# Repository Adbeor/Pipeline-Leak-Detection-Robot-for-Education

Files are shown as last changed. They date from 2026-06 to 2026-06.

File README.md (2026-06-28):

# PLDR-Edu: Open-Source Pipeline Leak Detection Robot 🤖💧

<div align="center">
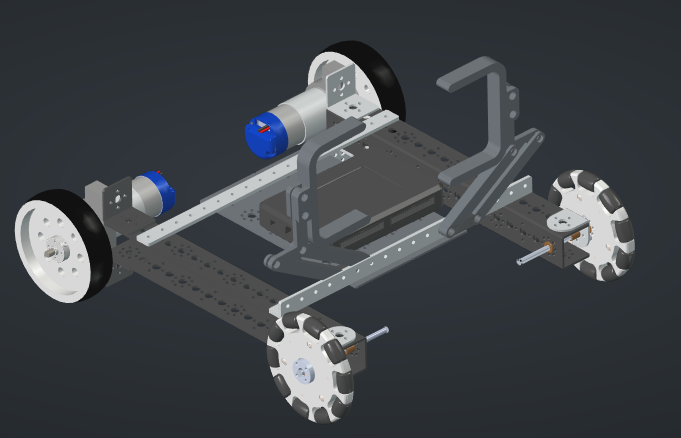
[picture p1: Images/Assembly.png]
PLDR-Edu Robot
  
</div>

This project introduces the **PLDR-Edu**, an open-source mobile robot designed as a project-based learning (PBL) platform for the **Mechatronic Systems Design** course at **UTEC**.

The system addresses the engineering challenge of inspecting a pressurized 3-inch PVC pipe and detecting simulated air leaks without human intervention. The robot encircles the pipe using a rigid two-clamp frame with 3D-printed arms, scanning it acoustically and visually without physical contact. Upon detection, a marker mechanism paints a reference dot directly on the pipe, and an acoustic alarm alerts the operator.

## 📋 Main Features & Contributions
- **Non-Contact Sweep:** The geometric constraint of the frame provides 360-degree coverage at a controlled stand-off distance. 
- **Acoustic Triangulation:** Captures and filters signals using three calibrated microphones targeting the characteristic broadband acoustic signal of pressurized air leaks.
- **Visual Confirmation:** A dedicated vision pipeline processes images to confirm the physical hole.
- **Contributions:** Generic microphone calibration process, vision-to-hardware data pipeline, and scalable scanning processes.
- **License:** CERN-OHL-P

## 🛠️ Hardware Architecture
The robot utilizes a multi-level control and processing architecture:
- **Structure & Actuation:** TETRIX® robotics kit combined with custom 3D-printed extensions.
- **Main Controller:** NI MyRIO running LabVIEW for locomotion and main logic.
- **Acoustic Processing:** ESP32 modules handling the signal from the microphones with band-pass filtering.
- **Computer Vision:** Raspberry Pi 3 (with optional Arty A7 100T FPGA support) dedicated to visual confirmation.

## 📂 Repository Structure
- `/CAD`: Individual CAD files and assemblies (.FCStd and .step formats).
- `/Electronics`: Electronic schematics and hardware files.
- `/Firmware`: Source code for the robot's control system.
- `/images`: Documentation images and renders.
- `/Docs`: Diagrams, schematics, and the full HardwareX article report.

---
*Developed by Adrian Becerra, Andrea Muñoz, Carlos Lam, Kiyomi Takahashi\**

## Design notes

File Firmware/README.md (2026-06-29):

# Firmware del Robot Inspector de Fugas de Tuberías

Este directorio contiene el firmware de control del microcontrolador **ESP32** encargado del procesamiento digital de señales acústicas (DSP) y sensores de proximidad ultrasónicos, así como las herramientas en **Python** para adquisición de datos, análisis espectral de fugas en tiempo real y visualización de registros.

---

## 📂 Estructura de Carpetas Organizada

La carpeta de Firmware se ha estructurado de la siguiente forma para separar el código de producción, los scripts de análisis y los datos recolectados:

```text
Firmware/
├── README.md               # Este archivo de documentación
└── ESP32/                  # Proyecto principal en ESP-IDF (C/C++)
    ├── main/               # Código fuente del firmware
    │   ├── main.c          # Código principal (Dual-Core: FFT + Sonar + Telemetría)
    │   ├── main_normal.c   # Versión simplificada del firmware principal
    │   ├── calibrate.c     # Rutina de calibración y prueba de sensores
    │   ├── CMakeLists.txt  # Configuración de compilación del módulo principal
    │   └── idf_component.yml # Dependencia oficial para la librería esp-dsp
    ├── scripts/            # Scripts en Python de análisis y telemetría
    │   ├── log_data.py     # Registro en vivo de telemetría UART a archivos CSV
    │   ├── plot_log.py     # Visualización gráfica de los históricos de sensores (CSV a PNG)
    │   ├── FFT.py          # Visualización en vivo y captura de espectros FFT por puerto serial
    │   ├── plot_spectrum.py # Capturador y promediador de firmas de fuga de frecuencia (Hz)
    │   └── robot_guide.py  # Script de guía interactiva durante experimentos en tuberías
    ├── data/               # Historial de registros CSV y gráficos generados
    │   ├── sensor_log_*.csv  # Logs crudos de pruebas
    │   ├── sensor_log_*.png  # Gráficas automáticas de presión y proximidad
    │   └── leak_signature_*.csv # Firmas espectrales de fugas capturadas
    ├── sdkconfig           # Configuración del proyecto ESP-IDF
    └── CMakeLists.txt      # Archivo de construcción global del proyecto
```

---

## ⚡ Arquitectura del Firmware (ESP32)

El firmware está desarrollado sobre **ESP-IDF v5.x/v6.x** utilizando capacidades **Dual-Core** y multitarea con **FreeRTOS** para garantizar procesamiento de audio en tiempo real y lecturas de telemetría sin latencia.

### Distribución de Tareas en Núcleos

```mermaid
graph TD
    subgraph ESP32
        subgraph Core0 [Core 0: Control & Telemetría]
            T1[hcsr04_uart_task]
            T1 -->|Lectura Secuencial| S1[6x Ultrasonidos HC-SR04]
            T1 -->|Envío Trama| U[UART2 TX GPIO 17]
        end
        subgraph Core1 [Core 1: Adquisición & DSP]
            T2[audio_fft_task]
            T2 -->|Lectura ADC1 CH4-7| M[4x Micrófonos Analógicos]
            T2 -->|Procesamiento| FFT[1024-pt FFT & Hann Window]
            FFT -->|Magnitud Acústica / Filtro 13-16 kHz| Q[Cola FreeRTOS]
        end
        Q -->|Resultados de FFT| T1
    end
    U -->|Trama: MAG:X.XXX,D:XX.X,P1...| myRIO[myRIO RX]
```

1. **Núcleo 1 (Procesamiento de Audio - `audio_fft_task`)**:
   - Muestrea secuencialmente **4 micrófonos analógicos** a una frecuencia de muestreo de **20 kHz por canal** usando el ADC1 (para no interferir con la antena WiFi/BT).
   - Aplica una ventana de **Hann** para reducir el leakage espectral y calcula una **FFT de 1024 puntos** por micrófono mediante hardware asistido por la librería **`esp_dsp`**.
   - Filtra y promedia las magnitudes en la banda crítica de fugas (**13 kHz – 16 kHz**).
   - Envía el promedio de la magnitud acústica (`MAG`) a una cola de FreeRTOS.

2. **Núcleo 0 (Proximidad y Telemetría - `hcsr04_uart_task`)**:
   - Realiza lecturas secuenciales de hasta **6 sensores de ultrasonido HC-SR04** para detección de obstáculos y posicionamiento del robot en la tubería.
   - Recibe la magnitud del análisis espectral de fugas (`MAG`) desde la cola.
   - Genera una trama estructurada y la envía a través de **UART2** (115200 baudios) al controlador de tracción (NI myRIO).

> [!IMPORTANT]
> **Trama de Telemetría UART:**
> `MAG:<Magnitud_Fuga>,D:<Distancia_HCSR04>,P1:<Proximidad1>,P2:<Proximidad2>,P3:<Proximidad3>\n`
> Esta trama es enviada continuamente para que el robot decida detenerse si detecta una fuga (alta `MAG`) o un obstáculo (baja `D` o valores de proximidad en `P1`/`P2`/`P3` por debajo de `PROXIMITY_THRESHOLD_CM`).

---

## 🔌 Asignación de Pines (Pinout)

Todos los sensores analógicos están conectados al bloque **ADC1** debido a restricciones de ESP-IDF cuando se activan módulos inalámbricos o de control.

| Sensor / Puerto | Pin GPIO (ESP32) | Función | Detalles / Canal ADC |
| :--- | :--- | :--- | :--- |
| **Micrófono 0** | GPIO 32 | Entrada Analógica | `ADC1_CH4` |
| **Micrófono 1** | GPIO 33 | Entrada Analógica | `ADC1_CH5` |
| **Micrófono 2** | GPIO 34 | Entrada Analógica | `ADC1_CH6` (Solo Entrada) |
| **Micrófono 3** | GPIO 35 | Entrada Analógica | `ADC1_CH7` (Solo Entrada) |
| **HC-SR04 Main (Distancia)** | TRIG: GPIO 4 / ECHO: GPIO 5 | Distancia Frontal | Sensor principal de trayectoria |
| **HC-SR04 P1** | TRIG: GPIO 18 / ECHO: GPIO 19| Detección de Pared 1 | Sensor de alineación lateral |
| **HC-SR04 P2** | TRIG: GPIO 21 / ECHO: GPIO 22| Detección de Pared 2 | Sensor de alineación lateral |
| **HC-SR04 P3** | TRIG: GPIO 23 / ECHO: GPIO 25| Detección de Pared 3 | Sensor de alineación lateral |
| **UART2 TX** | GPIO 17 | Transmisión de datos | Conexión al RX del controlador myRIO |
| **UART2 RX** | GPIO 16 | Recepción de datos | Sin uso en la versión actual |

---

## 🛠️ Compilación y Flasheo del Firmware

Se requiere tener instalado el entorno **ESP-IDF** (versión 5.1 o superior recomendada).

```bash
# 1. Navegar al proyecto ESP32
cd Firmware/ESP32

# 2. Configurar la arquitectura (ESP32 clásica)
idf.py set-target esp32

# 3. Compilar el proyecto
idf.py build

# 4. Flashear y abrir el monitor serial
# Reemplaza /dev/ttyUSB0 con tu puerto local asignado
idf.py -p /dev/ttyUSB0 flash monitor
```

---

## 🐍 Guía de Uso de Herramientas Python (scripts/)

Los scripts de Python permiten registrar y graficar experimentos en tiempo real conectando el ESP32 a la computadora vía USB-Serial.

> [!NOTE]
> Todos los scripts de Python han sido actualizados para guardar sus salidas automáticamente dentro de la carpeta `Firmware/ESP32/data/` para mantener ordenada la raíz del proyecto.

### 1. Visualización de Espectro en Tiempo Real (`FFT.py`)
Muestra un gráfico dinámico del espectro de frecuencia capturado por los micrófonos del robot.
```bash
python scripts/FFT.py --port /dev/ttyUSB0 --maxfreq 10000
```

### 2. Registro de Telemetría (`log_data.py`)
Captura los datos del puerto serial de telemetría y los guarda en un archivo estructurado CSV de forma continua.
```bash
python scripts/log_data.py --port /dev/ttyUSB0
# Genera: data/sensor_log_YYYYMMDD_HHMMSS.csv
```

### 3. Generación de Gráficas Estáticas (`plot_log.py`)
Genera automáticamente imágenes en formato PNG a partir de los datos crudos `.csv` guardados en la carpeta `data/`.
```bash
python scripts/plot_log.py data/sensor_log_20260619_171421.csv
# Genera: data/sensor_log_20260619_171421.png con trazas de magnitudes y distancias
```

### 4. Captura de Firmas Espectrales (`plot_spectrum.py`)
Muestra el espectro en tiempo real y permite promediar y exportar una firma de fuga definitiva.
* **Tecla `S`:** Presionar en la ventana de visualización para exportar la firma espectral promedio de la fuga a un archivo `.csv`.
```bash
python scripts/plot_spectrum.py --port /dev/ttyUSB0
# Genera: data/leak_signature_1781908096.csv
```

### 5. Guía de Experimentos (`robot_guide.py`)
Asistente interactivo en consola para documentar ensayos en la maqueta de tuberías, pidiendo descripciones de la prueba y registrando datos del comportamiento del robot paso a paso.
```bash
python scripts/robot_guide.py --port /dev/ttyUSB0
# Genera: data/robot_guide_log_YYYYMMDD_HHMMSS.csv
```

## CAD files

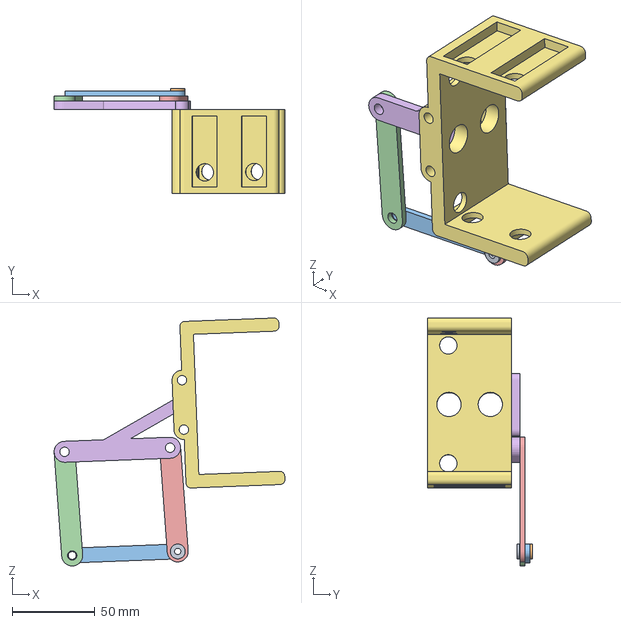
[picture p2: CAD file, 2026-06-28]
CAD/garras-Assembly.3mf
139.9 x 63.5 x 150.3 mm

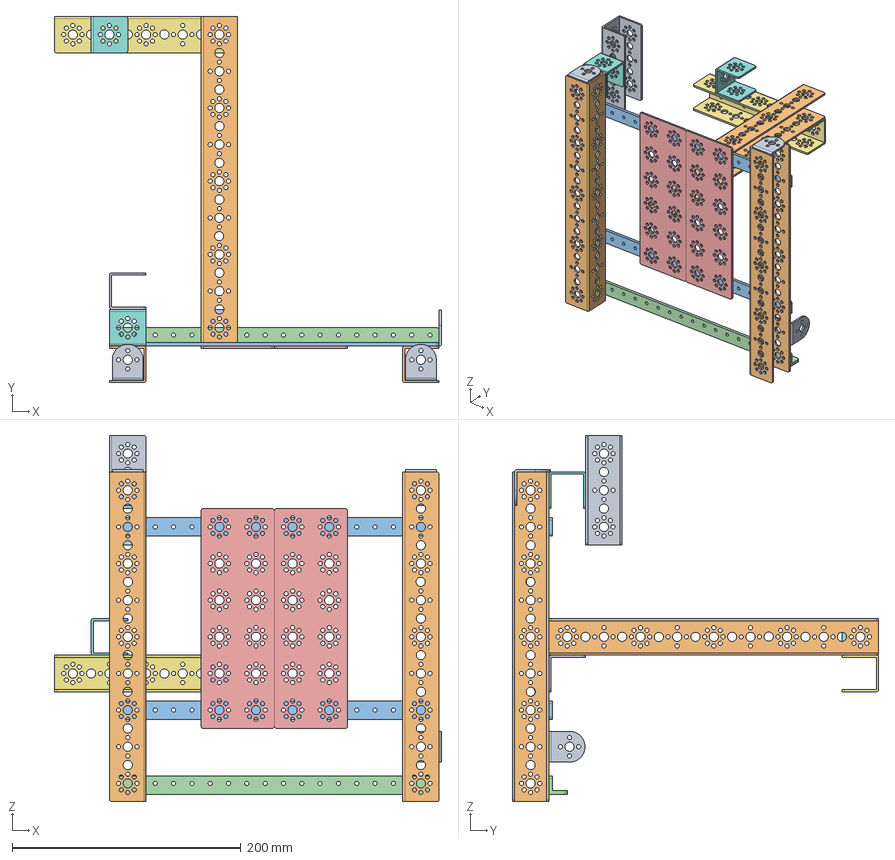
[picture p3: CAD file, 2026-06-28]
CAD/EnsambleMaestro.FCStd
338.0 x 320.0 x 320.0 mm
39062_TXM-LBrackets x 3
39068_TXM-288mmChannel x 3
39070_TXM-288mm Flat Bar x 2
39071_TXM-288mmAngle
39073_TXM-FlatBuildingPlates x 2
39281_TXM-InsideCornerBrackets
39067_TXM-160mmChannel
39065_TXM-32mmChannel x 2
39066_TXM-96mmChannel

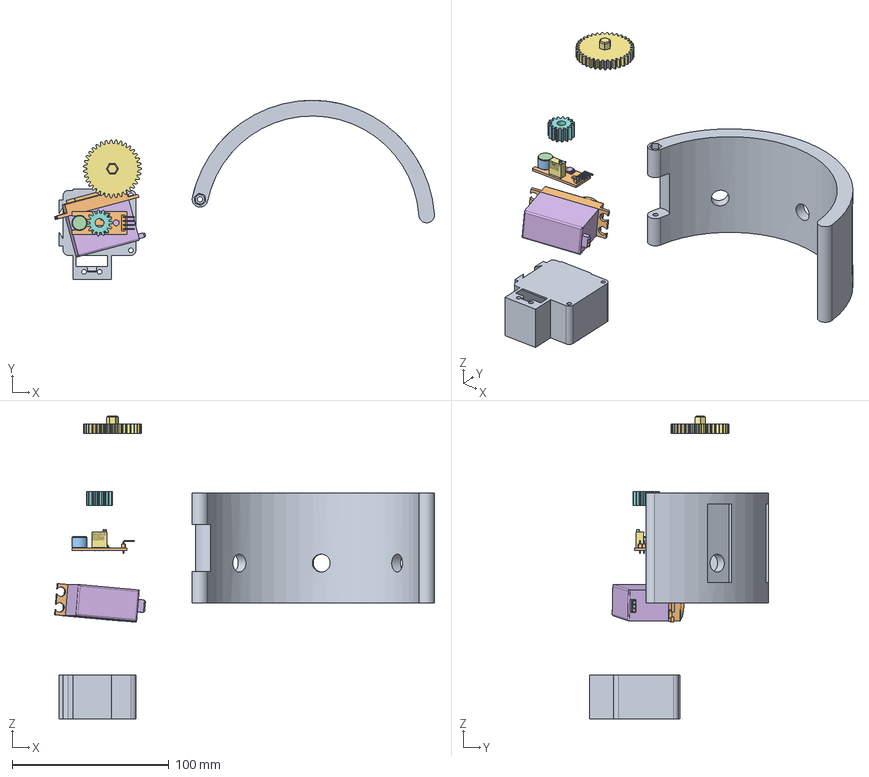
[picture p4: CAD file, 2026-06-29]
CAD/Garra2.FCStd
242.2 x 114.3 x 193.0 mm
Garra
Engrane_Garra
Engrane_servo
Base_Garra
HJX_Mike_PCB
Mike_housing
Mike_cap
Mike_terminal x 2
SOIC-8
Bao_3296_Body
Bao_3296_Adj_Trim
Bao_3296_Terminal x 3
1X4_Pin_Holder
90_Pin_M x 4

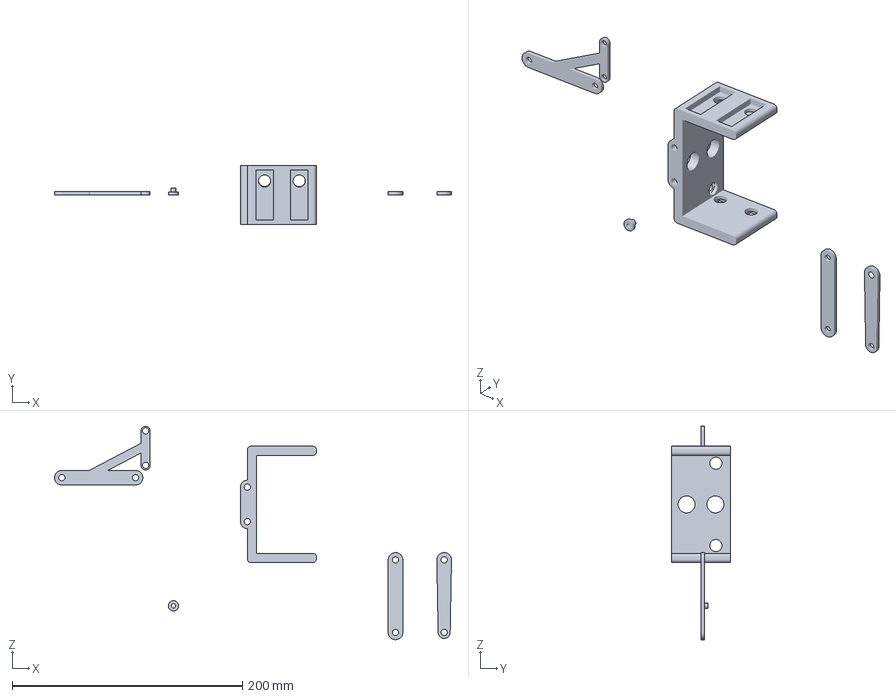
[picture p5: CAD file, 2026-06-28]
CAD/gcodes/garras-Part.3mf
344.7 x 51.0 x 185.4 mm

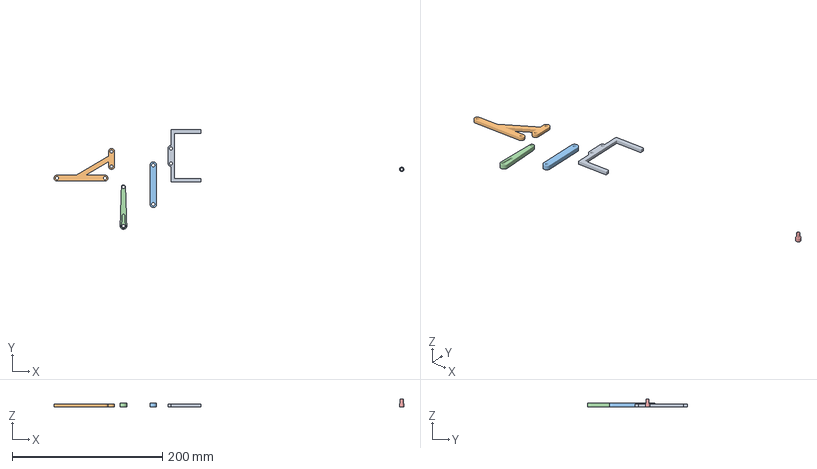
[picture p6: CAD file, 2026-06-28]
CAD/gcodes/garras-2.3mf
466.6 x 132.9 x 10.3 mm

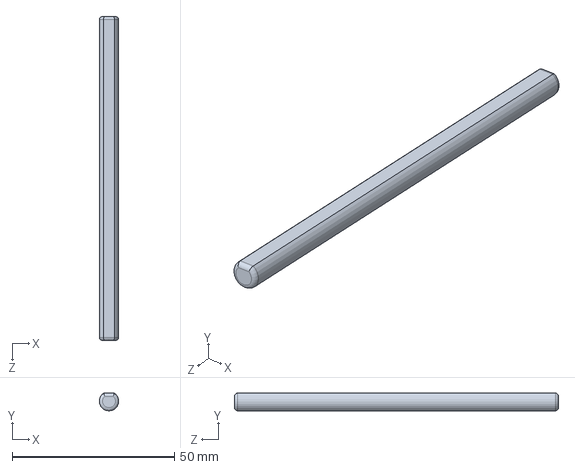
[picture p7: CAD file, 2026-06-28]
CAD/Piezas/Tetrix 6mm x 100mm Axle.SLDPRT
6.00 x 5.50 x 100.0 mm

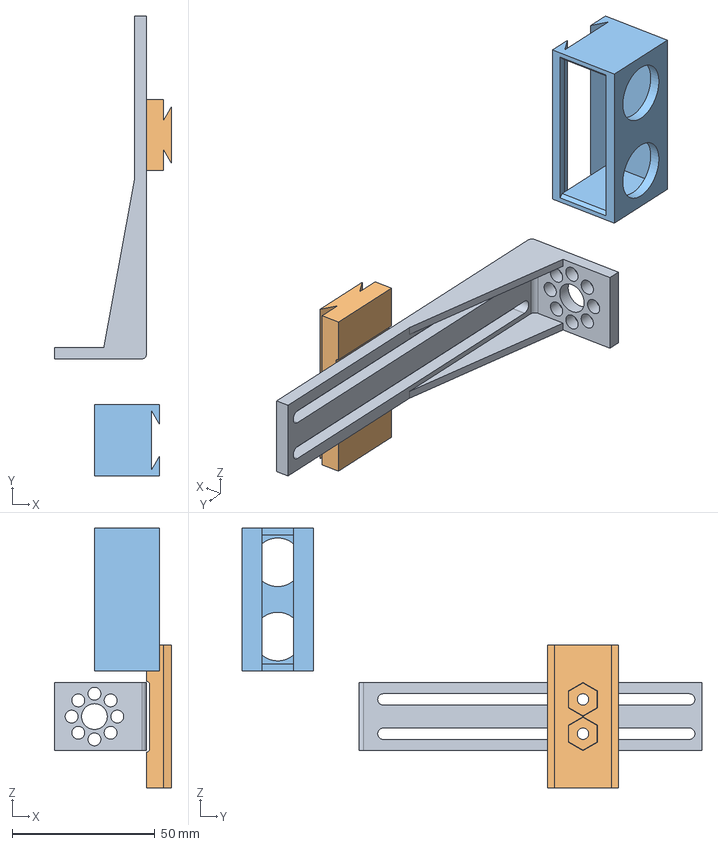
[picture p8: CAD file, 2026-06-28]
CAD/Soporte_Ultrasonido.FCStd
41.0 x 161.0 x 91.0 mm
SoporteVertical
Cuerpo001
Cuerpo002

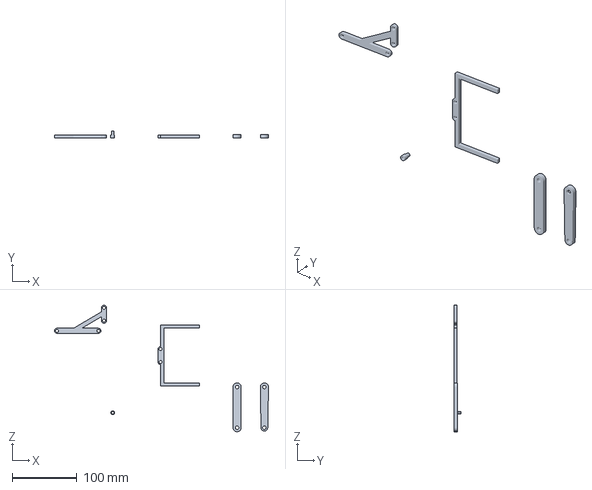
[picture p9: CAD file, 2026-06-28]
CAD/gcodes/garras-PartBody.3mf
331.7 x 10.3 x 196.2 mm

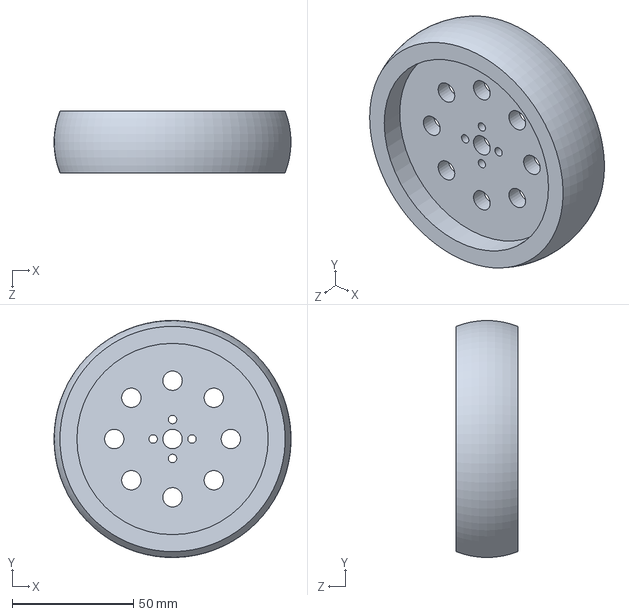
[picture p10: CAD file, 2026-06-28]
CAD/Piezas/Tetrix 4 inch Wheel.SLDPRT
97.6 x 97.6 x 25.4 mm

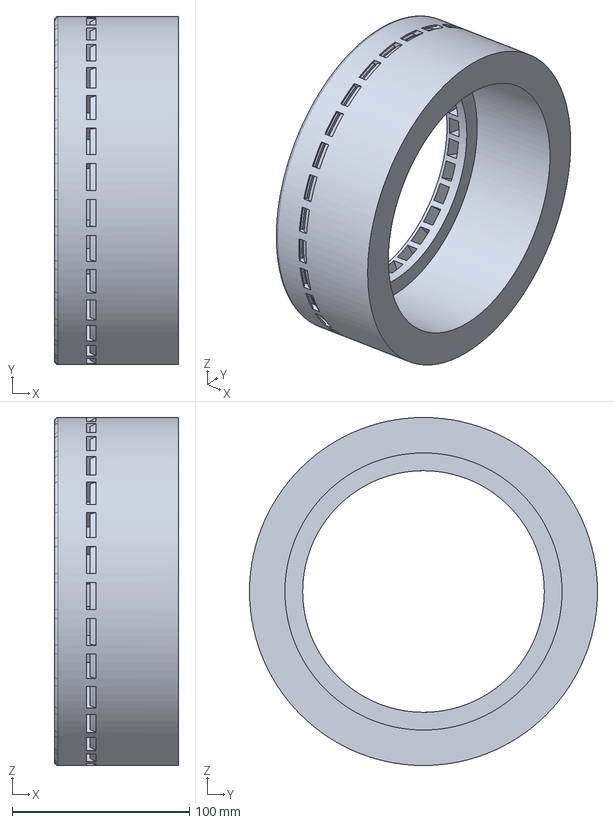
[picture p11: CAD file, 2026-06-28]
CAD/sibato.FCStd
70.0 x 196.2 x 196.2 mm

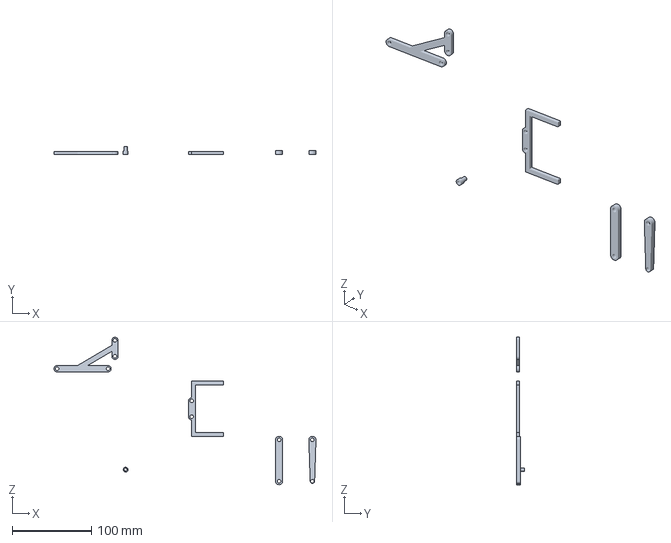
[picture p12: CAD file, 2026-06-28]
CAD/gcodes/garras-3.3mf
329.8 x 10.3 x 185.7 mm

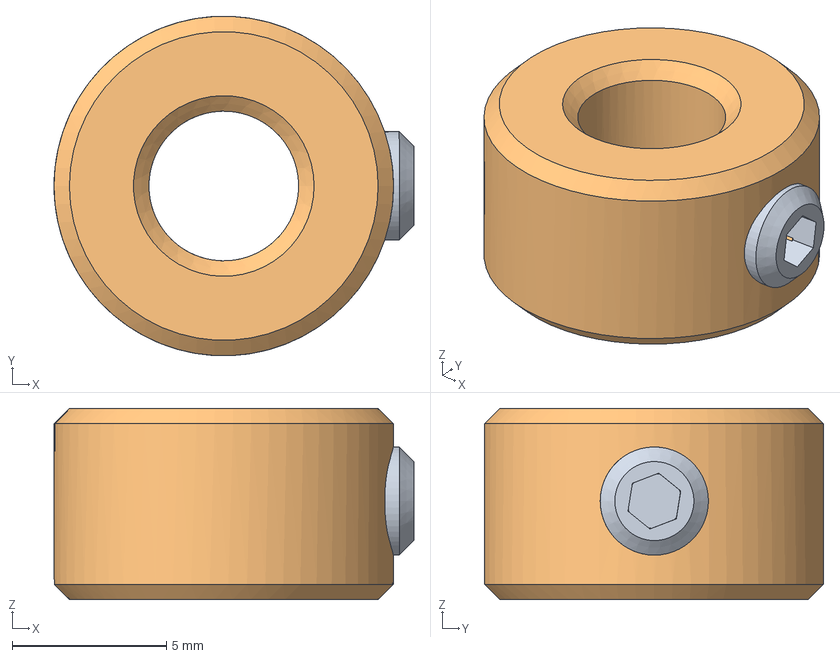
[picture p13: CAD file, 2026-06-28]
CAD/Piezas/Tetrix Axle Set Collar(2).step
11.7 x 11.0 x 6.20 mm

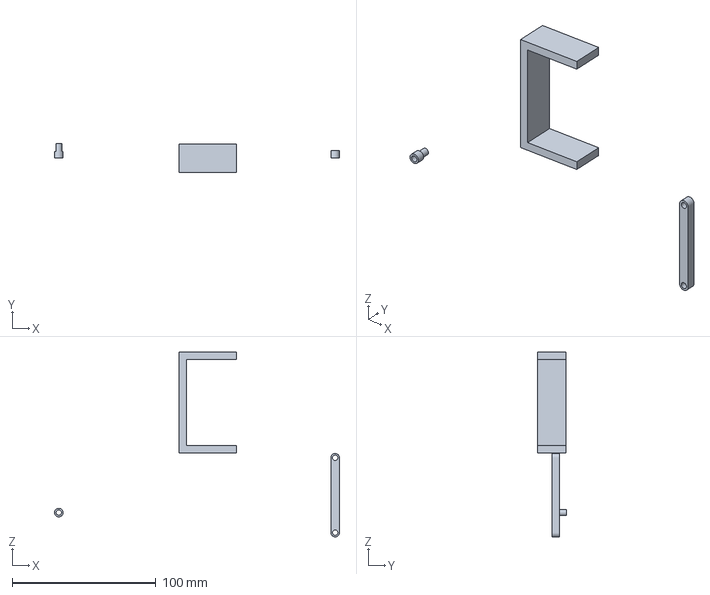
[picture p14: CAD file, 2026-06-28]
CAD/gcodes/garras_1.3mf
198.0 x 20.3 x 128.4 mm

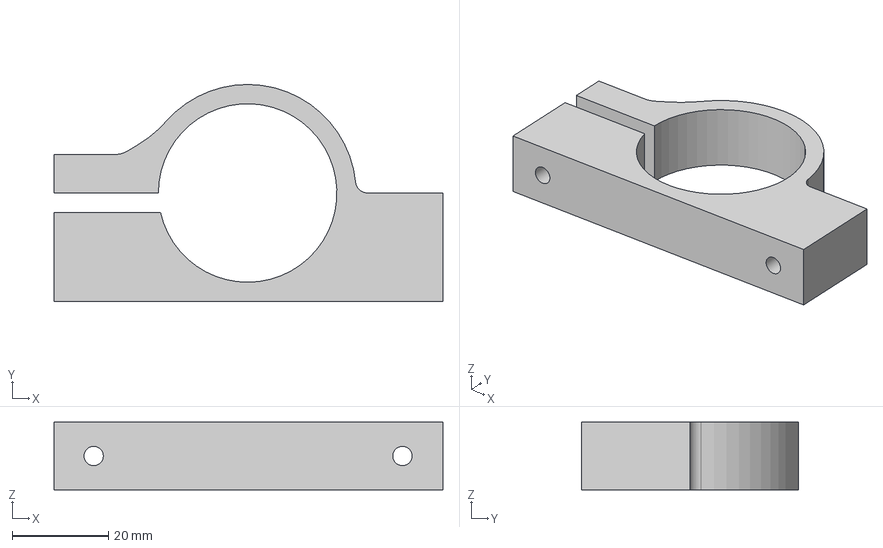
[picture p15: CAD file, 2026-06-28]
CAD/Piezas/motortarto.step
80.6 x 45.0 x 14.0 mm

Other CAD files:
CAD/gcodes/garras-4.3mf
CAD/Sin nombre.FCStd
CAD/Encaje_Motor.FCStd
CAD/gcodes/Encaje_Motor-Body.3mf
CAD/Piezas/MyRio.step
CAD/Piezas/Tetrix 4 inch Dual Omni Wheel(2).SLDPRT
CAD/Piezas/Tetrix 4 inch Dual Omni Wheel(2).step
CAD/Piezas/Tetrix 4 inch Wheel(2) - WHEEL 4.step
CAD/Piezas/Tetrix 4 inch Wheel(2).SLDPRT
CAD/Piezas/Tetrix Axle Hub With Set Screw(2) - Part 3.step
CAD/Piezas/Tetrix Axle Hub With Set Screw(2).SLDPRT
CAD/Piezas/Tetrix Axle Set Collar(2).SLDPRT
CAD/Piezas/Tetrix Bronze Bushing(2) - Chamfer1.step
CAD/Piezas/Tetrix Bronze Bushing(2).SLDPRT
CAD/Piezas/Tetrix Motor Shaft Hub With Set Screw(2).SLDPRT
CAD/Piezas/Tetrix Steel Axle 100mm(2).SLDPRT
CAD/Piezas/Tetrix Steel Axle 100mm.SLDPRT
CAD/Piezas/Tetrix TorqueNADO DC Motor(2).SLDPRT
CAD/Piezas/Tetrix TorqueNADO DC Motor(2).step
CAD/Piezas/Tetrix12V.step
CAD/Piezas/Tetrix12V_.SLDPRT
CAD/Piezas/axel.step
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

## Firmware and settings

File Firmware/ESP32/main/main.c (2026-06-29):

/**
 * @file main.c
 * @brief ESP32 Dual-Core: 4x Mic Analógico (FFT 13–16 kHz) + 4x HC-SR04
 *
 * ARQUITECTURA:
 *   Core 0 (Task: hcsr04_uart_task)
 *     - Lee 4× HC-SR04 secuencialmente
 *     - Recibe resultado FFT via Queue
 *     - Envía trama UART: MAG:X.XXX,D:XXX.X,P1:X,P2:X,P3:X\n
 *
 *   Core 1 (Task: audio_fft_task)
 *     - Muestrea 4 ADC en secuencia a ~160 kHz total (~40 kHz/canal)
 *     - Aplica ventana Hann + FFT de 1024 puntos por micrófono (esp_dsp)
 *     - Promedia magnitud en banda 13–16 kHz entre los 4 micrófonos
 *     - Envía resultado a Queue compartida
 *
 * PINES (todos en ADC1 para evitar conflicto con WiFi):
 *   Micrófonos:
 *     MIC0 → GPIO32 (ADC1_CH4)
 *     MIC1 → GPIO33 (ADC1_CH5)
 *     MIC2 → GPIO34 (ADC1_CH6)
 *     MIC3 → GPIO35 (ADC1_CH7)
 *
 *   HC-SR04 (TRIGGER / ECHO):
 *     HCSR04_MAIN (envía distancia)  → TRIG: GPIO 4  | ECHO: GPIO 5
 *     HCSR04_P1                      → TRIG: GPIO 18 | ECHO: GPIO 19
 *     HCSR04_P2                      → TRIG: GPIO 21 | ECHO: GPIO 22
 *     HCSR04_P3                      → TRIG: GPIO 23 | ECHO: GPIO 25
 *
 *   UART TX → GPIO 17 (UART2)   [conectar a RX del myRIO]
 *   UART RX → GPIO 16 (UART2)   [no usado, pero declarado]
 *
 * NOTA PINES ADC:
 *   GPIO32 y GPIO33 son bidireccionales; evita pull-ups/pull-downs activos
 *   en esos pines para no distorsionar la lectura analógica.
 *   GPIO34 y GPIO35 son input-only (no tienen driver de salida interno).
 *
 * DEPENDENCIAS (idf_component.yml o CMakeLists):
 *   - esp_adc
 *   - esp_timer
 *   - esp_dsp  (componente oficial: idf-extra-components/esp-dsp)
 *   - driver
 *   - freertos
 *
 * COMPILACIÓN:
 *   idf.py set-target esp32
 *   idf.py build flash monitor
 */

#include <stdio.h>
#include <string.h>
#include <math.h>
#include "freertos/FreeRTOS.h"
#include "freertos/task.h"
#include "freertos/queue.h"
#include "driver/gpio.h"
#include "driver/uart.h"
#include "esp_adc/adc_oneshot.h"
#include "esp_timer.h"
#include "esp_log.h"
#include "dsps_fft2r.h"   // esp-dsp: FFT radix-2
#include "dsps_wind.h"    // esp-dsp: ventanas

/* ─────────────────────────────────────────────
   CONSTANTES GENERALES
───────────────────────────────────────────── */
#define TAG                 "ESP32_SENSOR"

/* ADC / Audio */
#define NUM_MICS            4
#define FFT_SIZE            1024          // puntos por canal
#define SAMPLE_RATE_HZ      20000         // muestreo por canal (Hz) (bajado a 20 kHz para precisión del ADC)
#define BANDS_COUNT         32
#define BINS_PER_BAND       ( (FFT_SIZE / 2) / BANDS_COUNT ) // 512 / 32 = 16 bins por banda (~312.5 Hz)

static const float leak_pattern[22] = {
    0.2557f, 0.3818f, 0.1938f, 0.2244f, 0.2162f, 0.1818f, 0.2123f, 0.2085f,
    0.2575f, 0.2778f, 0.2957f, 0.2166f, 0.2527f, 0.1716f, 0.1454f, 0.1472f,
    0.1490f, 0.1499f, 0.1468f, 0.1158f, 0.1315f, 0.1473f
};

/* HC-SR04 */
#define NUM_HCSR04          6             // Número total de sensores HC-SR04
#define HCSR04_TIMEOUT_US   25000         // 25 ms → ~4.3 m máximo
#define PROXIMITY_THRESHOLD_CM 10.0f

/* UART */
#define UART_PORT           UART_NUM_2
#define UART_BAUD           115200
#define UART_TX_PIN         17
#define UART_RX_PIN         16
#define UART_BUF_SIZE       256

/* ─────────────────────────────────────────────
   PINES ADC (canales ADC1)
───────────────────────────────────────────── */
static const adc_channel_t adc_channels[] = {
    ADC_CHANNEL_4,   // GPIO32
    ADC_CHANNEL_5,   // GPIO33
    ADC_CHANNEL_6,   // GPIO34
    ADC_CHANNEL_7,   // GPIO35
};

static const gpio_num_t adc_gpios[] = {
    GPIO_NUM_32,
    GPIO_NUM_33,
    GPIO_NUM_34,
    GPIO_NUM_35,
};

/* ─────────────────────────────────────────────
   PINES HC-SR04
───────────────────────────────────────────── */
typedef struct {
    gpio_num_t trig;
    gpio_num_t echo;
} hcsr04_pins_t;

static const hcsr04_pins_t hcsr04[NUM_HCSR04] = {
    {GPIO_NUM_4,  GPIO_NUM_5},   // MAIN → envía distancia (D)
    {GPIO_NUM_18, GPIO_NUM_19},  // P1 (Derecha)
    {GPIO_NUM_21, GPIO_NUM_22},  // P2 (Izquierda)
    {GPIO_NUM_23, GPIO_NUM_25},  // P3 (Frente)
    {GPIO_NUM_26, GPIO_NUM_27},  // PCR (Cruzado)
    {GPIO_NUM_14, GPIO_NUM_15},  // PAT (Atrás)
};

/* ─────────────────────────────────────────────
   QUEUE INTER-CORE
───────────────────────────────────────────── */
static QueueHandle_t fft_result_queue;

/* ─────────────────────────────────────────────
   BUFFERS GLOBALES (Core 1 los usa exclusivamente)
───────────────────────────────────────────── */
// Cada buffer: parte real [0,2,4,...] y parte imaginaria [1,3,5,...] intercaladas
// esp_dsp trabaja con float interleaved: [r0,i0,r1,i1,...]
static float fft_buf[FFT_SIZE * 2];   // reutilizado para cada mic
static float hann_window[FFT_SIZE];
static int   adc_raw[NUM_MICS][FFT_SIZE];  // muestras crudas

/* ─────────────────────────────────────────────
   HANDLE ADC
───────────────────────────────────────────── */
static adc_oneshot_unit_handle_t adc_handle;

/* ══════════════════════════════════════════════
   FUNCIONES AUXILIARES
══════════════════════════════════════════════ */

/**
 * @brief Inicializa UART2 para comunicación con myRIO.
 */
static void uart_init(void)
{
    uart_config_t cfg = {
        .baud_rate  = UART_BAUD,
        .data_bits  = UART_DATA_8_BITS,
        .parity     = UART_PARITY_DISABLE,
        .stop_bits  = UART_STOP_BITS_1,
        .flow_ctrl  = UART_HW_FLOWCTRL_DISABLE,
    };
    ESP_ERROR_CHECK(uart_param_config(UART_PORT, &cfg));
    ESP_ERROR_CHECK(uart_set_pin(UART_PORT,
                                 UART_TX_PIN, UART_RX_PIN,
                                 UART_PIN_NO_CHANGE, UART_PIN_NO_CHANGE));
    ESP_ERROR_CHECK(uart_driver_install(UART_PORT, UART_BUF_SIZE * 2, 0, 0, NULL, 0));
    ESP_LOGI(TAG, "UART2 inicializado @ %d baud (TX=GPIO%d)", UART_BAUD, UART_TX_PIN);
}

/**
 * @brief Inicializa ADC1 en modo oneshot con atenuación 11 dB (0–3.3 V).
 */
static void adc_init(void)
{
    adc_oneshot_unit_init_cfg_t unit_cfg = {
        .unit_id  = ADC_UNIT_1,
        .ulp_mode = ADC_ULP_MODE_DISABLE,
    };
    ESP_ERROR_CHECK(adc_oneshot_new_unit(&unit_cfg, &adc_handle));

    adc_oneshot_chan_cfg_t chan_cfg = {
        .bitwidth = ADC_BITWIDTH_12,
        .atten    = ADC_ATTEN_DB_12,   // rango completo 0–3.3 V
    };
    for (int i = 0; i < NUM_MICS; i++) {
        ESP_ERROR_CHECK(adc_oneshot_config_channel(adc_handle, adc_channels[i], &chan_cfg));
        // Configurar pull-down para los pines bidireccionales GPIO32 y GPIO33
        if (adc_gpios[i] == GPIO_NUM_32 || adc_gpios[i] == GPIO_NUM_33) {
            gpio_set_pull_mode(adc_gpios[i], GPIO_PULLDOWN_ONLY);
        }
    }
    ESP_LOGI(TAG, "ADC1 inicializado (%d canales, 12-bit, atten 12 dB)", NUM_MICS);
}

/**
 * @brief Inicializa GPIO de todos los HC-SR04.
 */
static void hcsr04_gpio_init(void)
{
    for (int i = 0; i < NUM_HCSR04; i++) {
        gpio_reset_pin(hcsr04[i].trig);
        gpio_set_direction(hcsr04[i].trig, GPIO_MODE_OUTPUT);
        gpio_set_level(hcsr04[i].trig, 0);

        gpio_reset_pin(hcsr04[i].echo);
        gpio_set_direction(hcsr04[i].echo, GPIO_MODE_INPUT);
    }
    ESP_LOGI(TAG, "HC-SR04 GPIOs inicializados");
}

/**
 * @brief Mide distancia con HC-SR04.
 * @param idx  Índice del sensor (0–5)
 * @return Distancia en cm, o -1.0f si hay timeout.
 */
static float hcsr04_measure_cm(int idx)
{
    /* Pulso TRIGGER: 10 µs */
    gpio_set_level(hcsr04[idx].trig, 1);
    esp_rom_delay_us(10);
    gpio_set_level(hcsr04[idx].trig, 0);

    /* Esperar flanco de subida en ECHO */
    int64_t t_start = esp_timer_get_time();
    while (gpio_get_level(hcsr04[idx].echo) == 0) {
        if ((esp_timer_get_time() - t_start) > HCSR04_TIMEOUT_US) {
            return -1.0f;
        }
    }

    /* Medir duración del pulso ECHO */
    int64_t echo_start = esp_timer_get_time();
    while (gpio_get_level(hcsr04[idx].echo) == 1) {
        if ((esp_timer_get_time() - echo_start) > HCSR04_TIMEOUT_US) {
            return -1.0f;
        }
    }
    int64_t echo_end = esp_timer_get_time();

    /* Distancia: tiempo_us × velocidad_sonido / 2 */
    float duration_us = (float)(echo_end - echo_start);
    return (duration_us * 0.0343f) / 2.0f;   // cm
}

/* ══════════════════════════════════════════════
   TASK CORE 1 — AUDIO + FFT
══════════════════════════════════════════════ */
static void audio_fft_task(void *pvParameters)
{
    ESP_LOGI(TAG, "[Core1] audio_fft_task iniciado");

    /* Inicializar tabla FFT de esp_dsp (obligatorio una sola vez) */
    ESP_ERROR_CHECK(dsps_fft2r_init_fc32(NULL, FFT_SIZE));

    /* Generar ventana Hann */
    dsps_wind_hann_f32(hann_window, FFT_SIZE);

    /* Período entre muestras para mantener 20 kHz (50 µs) */
    const int64_t sample_period_us = 1000000LL / SAMPLE_RATE_HZ;

    while (1) {
        float band_magnitude_sum = 0.0f;
        int active_mics_count = 0;
        static uint32_t last_log_time[4] = {0, 0, 0, 0};

        for (int m = 0; m < NUM_MICS; m++) {
            /* ── 1. MUESTREO secuencial de 1024 muestras para el micrófono 'm' ── */
            for (int n = 0; n < FFT_SIZE; n++) {
                int64_t t_sample = esp_timer_get_time();
                adc_oneshot_read(adc_handle, adc_channels[m], &adc_raw[m][n]);
                
                /* Esperar para mantener los 20 kHz por canal */
                int64_t elapsed = esp_timer_get_time() - t_sample;
                if (elapsed < sample_period_us) {
                    esp_rom_delay_us((uint32_t)(sample_period_us - elapsed));
                }
            }

            /* ── Chequeo de conexión/funcionamiento del micrófono ── */
            float sum_raw = 0.0f;
            for (int n = 0; n < FFT_SIZE; n++) {
                sum_raw += adc_raw[m][n];
            }
            float avg_raw = sum_raw / FFT_SIZE;

            float sum_diff = 0.0f;
            for (int n = 0; n < FFT_SIZE; n++) {
                sum_diff += fabsf((float)adc_raw[m][n] - avg_raw);
            }
            float avg_diff = sum_diff / FFT_SIZE;

            // Si está desconectado (pull-down a 0V o corto a 3.3V)
            if (avg_raw < 500.0f || avg_raw > 3500.0f) {
                uint32_t now = esp_log_timestamp();
                if (now - last_log_time[m] > 5000) {
                    ESP_LOGW(TAG, "Mic %d Disconnected (Out of Bounds): avg_raw=%.1f, avg_diff=%.1f", m, avg_raw, avg_diff);
                    last_log_time[m] = now;
                }
                continue; // saltear procesamiento de este mic y seguir con el siguiente
            }

            /* ── 2. Cargar muestras en el buffer e implementar ventana Hann ── */
            for (int n = 0; n < FFT_SIZE; n++) {
                float sample = (float)(adc_raw[m][n] - 2048);  // centro en 0
                fft_buf[2 * n]     = sample * hann_window[n];  // parte real
                fft_buf[2 * n + 1] = 0.0f;                     // parte imaginaria
            }

            /* ── 3. FFT radix-2 y ordenamiento bit-reverse ── */
            dsps_fft2r_fc32(fft_buf, FFT_SIZE);
            dsps_bit_rev_fc32(fft_buf, FFT_SIZE);

            /* ── 4. Agrupar en 32 bandas ── */
            float live_bands[BANDS_COUNT] = {0};
            for (int b = 0; b < BANDS_COUNT; b++) {
                float sum_mag = 0.0f;
                int start_bin = b * BINS_PER_BAND;
                int end_bin = (b + 1) * BINS_PER_BAND;

                for (int k = start_bin; k < end_bin; k++) {
                    if (k < 5) {
                        continue;
                    }
                    float re = fft_buf[2 * k];
                    float im = fft_buf[2 * k + 1];
                    sum_mag += sqrtf(re * re + im * im);
                }

                int actual_bins = (b == 0) ? (BINS_PER_BAND - 5) : BINS_PER_BAND;
                live_bands[b] = (actual_bins > 0) ? (sum_mag / actual_bins) : 0.0f;
            }

            /* ── 5. Calcular Similitud y Energía Absoluta (Filtrado por firma) ── */
            float live_norm = 0.0f;
            for (int b = 10; b < BANDS_COUNT; b++) {
                live_norm += live_bands[b] * live_bands[b];
            }
            live_norm = sqrtf(live_norm);

            float similarity = 0.0f;
            if (live_norm > 0.01f) {
                for (int b = 10; b < BANDS_COUNT; b++) {
                    similarity += (live_bands[b] / live_norm) * leak_pattern[b - 10];
                }
            }

            // Calculamos la energía absoluta promedio en las bandas de la fuga (3.1 a 10 kHz)
            float absolute_energy = 0.0f;
            for (int b = 10; b < BANDS_COUNT; b++) {
                absolute_energy += live_bands[b];
            }
            absolute_energy /= 22.0f; // Promedio de las 22 bandas

            // Magnitud combinada: Energía * Similitud^2
            float rel_magnitude = absolute_energy * similarity * similarity;
            band_magnitude_sum += rel_magnitude;
            active_mics_count++;
        }

        /* Promedio final entre los micrófonos conectados/activos */
        float avg_magnitude;
        if (active_mics_count > 0) {
            avg_magnitude = band_magnitude_sum / active_mics_count;
        } else {
            avg_magnitude = -1.0f; // Todos están desconectados
        }

        /* ── 3. Enviar resultado a Core 0 via Queue ── */
        // Bloqueo máximo 0 ms: si la queue está llena, se descarta y se recalcula
        if (xQueueOverwrite(fft_result_queue, &avg_magnitude) != pdTRUE) {
            ESP_LOGW(TAG, "Queue FFT llena, dato descartado");
        }
        // Nota: xQueueOverwrite siempre sobreescribe (queue de longitud 1)

        // Evitar que se active el Watchdog (TWDT) en el Core 1 y reducir uso de CPU
        vTaskDelay(pdMS_TO_TICKS(50));
    }
}

/* ══════════════════════════════════════════════
   TASK CORE 0 — HC-SR04 + UART
══════════════════════════════════════════════ */
static void hcsr04_uart_task(void *pvParameters)
{
    ESP_LOGI(TAG, "[Core0] hcsr04_uart_task iniciado");

    char uart_buf[UART_BUF_SIZE];
    float fft_magnitude = 0.0f;

    while (1) {
        /* ── 1. Leer último resultado FFT disponible (no bloqueante) ── */
        xQueuePeek(fft_result_queue, &fft_magnitude, 0);

        /* ── 2. Leer HC-SR04 MAIN (índice 0) → distancia ── */
        float dist_main = hcsr04_measure_cm(0);
        vTaskDelay(pdMS_TO_TICKS(10));   // espera entre sensores (evita interferencia acústica)

        /* ── 3. Leer HC-SR04 P1, P2, P3 → proximidad binaria ── */
        int prox[3];
        for (int i = 1; i <= 3; i++) {
            float d = hcsr04_measure_cm(i);
            if (d < 0.0f) {
                prox[i - 1] = -1;  // Desconectado o error
            } else if (d <= PROXIMITY_THRESHOLD_CM) {
                prox[i - 1] = 1;   // Obstáculo detectado
            } else {
                prox[i - 1] = 0;   // Sin obstáculo
            }
            vTaskDelay(pdMS_TO_TICKS(10));
        }

        /* ── 4. Leer HC-SR04 PCR, PAT (índices 4 y 5) → distancias continuas ── */
        float dist_cruzado = hcsr04_measure_cm(4);
        vTaskDelay(pdMS_TO_TICKS(10));
        float dist_atras = hcsr04_measure_cm(5);
        vTaskDelay(pdMS_TO_TICKS(10));

        /* ── 5. Armar y enviar trama UART y Logs ── */
        int len = snprintf(uart_buf, sizeof(uart_buf),
                           "MAG:%.4f,D:%.1f,P1:%d,P2:%d,P3:%d,PCR:%.1f,PAT:%.1f\n",
                           fft_magnitude, dist_main, prox[0], prox[1], prox[2], dist_cruzado, dist_atras);
        
        /* Enviar trama cruda a myRIO por UART2 (Termina en \n) */
        uart_write_bytes(UART_PORT, uart_buf, len);

        /* Enviar a la Laptop por el cable USB usando el sistema de Logs de ESP-IDF */
        // Nota: Le quitamos el '\n' al string original pasándolo con "%.*s" y (len - 1)
        // porque ESP_LOGI ya añade su propio salto de línea al final de forma automática.
        ESP_LOGI(TAG, "DATA -> %.*s", len - 1, uart_buf);

        // Pequeño yield para no bloquear el scheduler del Core 0
        vTaskDelay(pdMS_TO_TICKS(1));
    }
}

/* ══════════════════════════════════════════════
   APP MAIN
══════════════════════════════════════════════ */
void app_main(void)
{
    ESP_LOGI(TAG, "=== ESP32 Mic-FFT + HC-SR04 ===");
    ESP_LOGI(TAG, "FFT: %d pts | Fs: %d Hz | Deteccion de firma activa",
             FFT_SIZE, SAMPLE_RATE_HZ);

    /* ── Inicializar periféricos ── */
    uart_init();
    adc_init();
    hcsr04_gpio_init();

    /* ── Queue de longitud 1 (siempre tiene el último valor FFT) ── */
    fft_result_queue = xQueueCreate(1, sizeof(float));
    configASSERT(fft_result_queue);

    /* ── Rellenar queue con 0 para que Core 0 no quede bloqueado ── */
    float init_val = 0.0f;
    xQueueSend(fft_result_queue, &init_val, 0);

    /* ── Crear tareas pinned a su core ── */
    xTaskCreatePinnedToCore(
        audio_fft_task,
        "audio_fft",
        8192,           // stack (bytes): FFT necesita bastante
        NULL,
        5,              // prioridad alta
        NULL,
        1               // Core 1
    );

    xTaskCreatePinnedToCore(
        hcsr04_uart_task,
        "hcsr04_uart",
        4096,
        NULL,
        5,
        NULL,
        0               // Core 0
    );

    ESP_LOGI(TAG, "Tasks creadas. Sistema corriendo.");
    // app_main puede terminar; las tasks siguen vivas
}

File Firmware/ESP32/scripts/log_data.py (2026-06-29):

#!/usr/bin/env python3
# -*- coding: utf-8 -*-
"""
Registrador de Datos en Tiempo Real (Data Logger) para ESP32
Guarda la trama de datos con marcas de tiempo precisas en un archivo CSV.
Requisitos: pip install pyserial
Uso: python3 log_data.py [puerto_serial]
"""

import sys
import os
import time
import datetime
import re
import serial
import serial.tools.list_ports

def find_esp32_port():
    """Busca automáticamente el puerto COM del ESP32."""
    ports = list(serial.tools.list_ports.comports())
    usb_ports = [p.device for p in ports if any(x in p.description.upper() for x in ['USB', 'UART', 'ACM', 'CH340', 'CP210'])]
    if usb_ports:
        return usb_ports[0]
    elif ports:
        return ports[0].device
    return None

def main():
    # Selección de puerto
    if len(sys.argv) > 1:
        port = sys.argv[1]
    else:
        port = find_esp32_port()
        if not port:
            print("ERROR: No se encontró ningún puerto USB-Serial activo.")
            print("Conecta el ESP32 o especifica el puerto: python3 log_data.py /dev/ttyUSB0")
            sys.exit(1)
            
    print(f"Conectando a {port} a 115200 baudios...")
    
    try:
        ser = serial.Serial(port, 115200, timeout=1)
        ser.reset_input_buffer()
    except Exception as e:
        print(f"ERROR: No se pudo abrir el puerto {port}: {e}")
        sys.exit(1)

    # Crear el archivo CSV
    timestamp_str = datetime.datetime.now().strftime("%Y%m%d_%H%M%S")
    os.makedirs("data", exist_ok=True)
    filename = os.path.join("data", f"sensor_log_{timestamp_str}.csv")
    
    print(f"Creando archivo de registro: {filename}")
    try:
        f = open(filename, 'w')
        f.write("Timestamp,Epoch_Time_ms,MAG,D,P1,P2,P3,PCR,PAT,Tag\n")
        f.flush()
    except Exception as e:
        print(f"ERROR: No se pudo crear el archivo {filename}: {e}")
        ser.close()
        sys.exit(1)

    # Expresión regular para parsear la trama: MAG:%.4f,D:%.1f,P1:%d,P2:%d,P3:%d (opcionalmente con PCR y PAT)
    data_pattern = re.compile(r"MAG:([-\d.]+),D:([-\d.]+),P1:([-\d]+),P2:([-\d]+),P3:([-\d]+)(?:,PCR:([-\d.]+),PAT:([-\d.]+))?")

    # Inicializar matplotlib para tiempo real de forma segura (tolerante a fallos de DISPLAY)
    has_matplotlib = False
    try:
        import matplotlib
        import matplotlib.pyplot as plt
        from matplotlib.widgets import Button
        
        plt.style.use('dark_background')
        fig, ax = plt.subplots(figsize=(10, 5))
        fig.canvas.manager.set_window_title(f"Registro en Vivo: {filename}")
        
        # Dejar espacio en la parte inferior para el botón
        plt.subplots_adjust(bottom=0.22)
        
        line_plot, = ax.plot([], [], color='#00f0ff', linewidth=2.0, label="Magnitud (MAG)")
        ax.set_ylabel("Magnitud de Fuga (MAG)", color='#00f0ff', fontsize=11)
        ax.set_xlabel("Tiempo Relativo (segundos)", fontsize=11, color='#aaaaaa')
        ax.grid(True, linestyle='--', alpha=0.3)
        ax.set_title("Monitoreo de Intensidad Acústica en Tiempo Real", fontsize=12, fontweight='bold')
        
        # Crear botón interactivo para marcar fugas
        ax_btn = plt.axes([0.4, 0.04, 0.2, 0.075])
        btn_fuga = Button(ax_btn, '¡MARCAR FUGA!', color='#ff3333', hovercolor='#ff5555')
        btn_fuga.label.set_color('white')
        btn_fuga.label.set_weight('bold')
        
        manual_leak_flag = False
        def on_click(event):
            nonlocal manual_leak_flag
            manual_leak_flag = True
            print("\n[MARCA MANUAL] >>> ¡Fuga marcada por el usuario! <<<")
            
        btn_fuga.on_clicked(on_click)
        
        plot_times = []
        plot_mags = []
        start_time_ms = None
        last_plot_update = 0.0
        
        plt.ion()
        plt.show(block=False)
        has_matplotlib = True
        print(">>> Gráfico en tiempo real con botón interactivo activado.")
    except Exception as e:
        print(f"ADVERTENCIA: No se pudo iniciar el gráfico en tiempo real ({e}).")
        print("El registro continuará únicamente en la consola y en el archivo CSV.")

    print("\n>>> INICIANDO REGISTRO DE DATOS. Presiona Ctrl+C para detener y finalizar.")
    print("-" * 85)
    print(f"{'Marca de Tiempo':<24} | {'MAG':<10} | {'Dist. (D)':<10} | {'P1':<5} | {'P2':<5} | {'P3':<5}")
    print("-" * 85)

    samples_count = 0
    try:
        while True:
            if ser.in_waiting > 0:
                try:
                    # Leer línea y decodificar
                    line = ser.readline().decode('utf-8', errors='ignore').strip()
                except Exception:
                    continue
                
                # Buscar patrón en la línea
                match = data_pattern.search(line)
                if match:
                    # Obtener marcas de tiempo de la laptop
                    now = datetime.datetime.now()
                    now_str = now.strftime("%Y-%m-%d %H:%M:%S.%f")[:-3] # Con milisegundos
                    epoch_ms = int(time.time() * 1000)

                    # Extraer variables (y valores opcionales PCR/PAT continuos)
                    mag_val = match.group(1)
                    d_val = match.group(2)
                    p1_val = match.group(3)
                    p2_val = match.group(4)
                    p3_val = match.group(5)
                    pcr_val = match.group(6) if match.group(6) is not None else "-1.0"
                    pat_val = match.group(7) if match.group(7) is not None else "-1.0"

                    # Determinar si hay etiqueta manual
                    tag_str = ""
                    if has_matplotlib and manual_leak_flag:
                        tag_str = "FUGA"

                    # Guardar en CSV
                    f.write(f"{now_str},{epoch_ms},{mag_val},{d_val},{p1_val},{p2_val},{p3_val},{pcr_val},{pat_val},{tag_str}\n")
                    f.flush() # Guardar inmediatamente en disco
                    samples_count += 1

                    # Imprimir en consola en tiempo real
                    if tag_str == "FUGA":
                        print(f"{now_str:<24} | {mag_val:<10} | {d_val + ' cm':<10} | {p1_val:<5} | {p2_val:<5} | {p3_val:<5} | <<< FUGA MANUAL >>>")
                    else:
                        print(f"{now_str:<24} | {mag_val:<10} | {d_val + ' cm':<10} | {p1_val:<5} | {p2_val:<5} | {p3_val:<5}")
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

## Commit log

2026-05-11 chore: Organizacion
    [EnsambleMaestro.FCStd, MyRio.step, PowerWheel.FCStd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]
2026-05-11 cambios ensamble garra
    [EnsambleMaestro.FCStd]
2026-06-28 freecad gallery action
    [Encaje_Motor-Body.3mf, Encaje_Motor.FCStd, Encaje_Motor.yaml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]
2026-06-28 configuracion multi-body
    [Soporte_Ultrasonido.FCStd, caster.FCStd, garras.FCStd]
2026-06-28 Fix preprocess script: filter sub-features and evaluate names before close
2026-06-29 Organize firmware directory, update python data paths, and add detailed README
    [leak_signature_1781821891.csv, leak_signature_1781822076.csv, leak_signature_1781822106.csv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]
2026-06-29 Fix split parts export: isolate shape into CombinedGalleryModel to prevent empty STL outputs
2026-06-29 Add Micro part to Garra2 design and update build pipeline rules
    [Garra2.FCStd]
